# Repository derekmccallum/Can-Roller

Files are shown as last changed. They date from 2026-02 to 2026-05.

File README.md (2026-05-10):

# Can-Roller

Arduino driven device to roll up to 12 drink cans in unison for filming purposes

## Hardware

- 1 x Arduino CNC shield v3 with DRV8825 motor drivers
- 1 x Elegoo Uno R3
- 2 x HANPOSE 17HS4401-S 40mm Nema 17 Stepper Motor 42 Motor 42BYGH 1.7A 40N.cm 4-lead Motor
- 2 x GT2 2mm Pitch 6mm Width Closed Loop Synchronous Timing Belt 750 teeth 1500mm
- 2 x Machifit GT2 Timing Pulley 20 Teeth Synchronous Wheel Inner Diameter 5mm for 6mm Width Belt
- 4 x GT2 Idler Pulley 20 Teeth

## Control Input Features

| Feature | Ver | IO Pin | Description | Wiring |
|---|----|---|---|---|
| START button | v1 | A0 | If idle: start run (planned 5s total). If running: cancel and ramp down smoothly from current speed, then stop | Buttons wired to GND, use INPUT_PULLUP (pressed = LOW) |
| REVERSE button | v1 | A1 | Toggles travel direction | Buttons wired to GND, use INPUT_PULLUP (pressed = LOW) |
| SPEED pot | v1 | A2 | Sets cruise step rate | 5V → end, A2 → wiper, GND → other end |
| RUNTIME pot | v2 | A3 | Sets run time | 5V → end, A3 → wiper, GND → other end |

## File Versions
| File - Version | Description |
|---|---|
| can-roller-v1.ino | UNO + CNC Shield V3 + (2x) DRV8825<br>- START button (A0):<br>&nbsp;&nbsp;&nbsp;&nbsp;* if idle: start run (according to set runtime)<br>&nbsp;&nbsp;&nbsp;&nbsp;* if running: cancel and ramp down smoothly from CURRENT speed, then stop<br>- REVERSE button (A1): toggles direction for NEXT run only<br>- SPEED pot (A2): read once at start, sets cruise steps/sec (no mid-run updates)<br>- Soft start/stop: 0.5s ramp up / 0.5s ramp down<br>- DDS/phase-accumulator stepping (smooth, low jitter)<br>Buttons wired to GND, using INPUT_PULLUP (pressed = LOW) |
| can-roller-v2.ino | **New Feature: Variable Runtime Control**<br>- Added **RUNTIME pot** on analog pin **A3** for adjustable run duration (3-10 seconds)<br>- Runtime is read and latched when START button is pressed<br>- Replaces fixed 8-second duration from Version 1<br><br>**Hardware Change:**<br>- Add potentiometer to A3 (wired same as other pots: 5V → end, A3 → wiper, GND → other end)<br><br>**Control Summary:**<br>**A0**: START button - starts run or cancels mid-run<br>**A1**: REVERSE button - toggles direction for next run<br>**A2**: SPEED pot - read once at start, sets cruise (1000-9500 steps/sec)<br>**A3**: RUNTIME pot - sets run duration (3-10 seconds) ⭐ NEW<br><br>All other features unchanged: 0.5s soft start/stop, DDS stepping, smooth cancellation. |
| can-roller-v3.ino | **New Feature: Cruise speed variation during runtime**<br>1. Multi-Layer Noise Filtering:<br>Implemented moving average filter (5 samples) - smooths out electrical noise spikes<br>Rate limiting (2000 steps/sec² max change) - prevents sudden jerks from pot movements<br>Periodic sampling (every 50ms) - reduces ADC noise impact.<br><br>2. How It Works:<br>Raw Pot → Moving Average → Rate Limiter → Motor Speed<br>  (noisy) (smoothed) (gradual) (smooth)<br><br>**Control Summary:**<br>**A0**: START button - starts run or cancels mid-run<br>**A1**: REVERSE button - toggles direction for next run<br>**A2**: SPEED pot - sets cruise (1000-9500 steps/sec)<br>**A3**: RUNTIME pot - sets run duration (3-10 seconds)<br><br>All other features unchanged: 0.5s soft start/stop, DDS stepping, smooth cancellation. |
| can-roller-v4.ino | **New Feature: Dynamic reverse while running**<br>- REVERSE button behavior updated on **A1**:<br>&nbsp;&nbsp;&nbsp;&nbsp;* If idle: toggles direction for the next run only<br>&nbsp;&nbsp;&nbsp;&nbsp;* If running: performs normal ramp-down, toggles direction, waits a defined period, then restarts with normal ramp-up<br>- START button behavior unchanged: start when idle, graceful cancel when running<br>- SPEED (A2) and RUNTIME (A3) behavior unchanged from v3<br><br>Maintains soft start/stop profile and DDS stepping while adding in-run direction change handling. |
CNC Shield v3

## Power & step config

12V: 1/8 micro-stepping
Set jumpers MS1 ON, MS2 ON, MS3 OFF → 1600 steps/rev

	• DRV8825 @ 1/8 microstepping ⇒ 1600 steps/rev (200 × 8)
	• Can diameter ≈ 66 mm ⇒ circumference C ≈ 207.35 mm
	• GT2 pitch = 2 mm ⇒ belt travel per motor rev = 2 × teeth (mm)
	• Ideal no-slip rolling (and cans are constrained from translating)

Motor speed from step rate (independent of pulley teeth):
	• At 1000 steps/s: motor = 1000/1600 = 0.625 rps
	• At 9500 steps/s: motor = 9500/1600 = 5.9375 rps

Belt speed = motor_rps × (2×teeth)
Can speed (rev/s) = belt_speed / 207.35
 
A slave to X
	• Place a jumper on A → X

This electrically connects:
	• A_STEP → X_STEP
	• A_DIR  → X_DIR

So:
	• Both motors receive the same STEP and DIR signals
	• Arduino code only needs to drive X
	• A direction reversed owing to mounting

## DRV8825 Current Setting
### Configuration:
#### Stepper Motor: HANPOSE 17HS4401-S
• Rated Current: 1.7A per phase<br>
• Holding Torque: 40 N·cm (0.4 N·m)<br>
• Type: 4-lead bipolar<br>

#### DRV8825 Driver:
Vref measured (from pot centre arm to Gnd): 0.7V<br>
Current sense resistors: 0.1Ω (standard on most DRV8825 boards)

### Calculated Current Output:
Using the DRV8825 formula:<br>
Current Limit = Vref / (8 × Rs)<br>
Where:<br>
• Vref = 0.7V (your measurement)<br>
• Rs = 0.1Ω (sense resistor value)<br>

Current = 0.7V / (8 × 0.1Ω) = 0.875A

### Analysis:
✅ Safe Configuration
The motor is rated for 1.7A, and we're running it at 0.875A (≈51% of rated current).<br>
Pros:<br>
• Motors run cooler<br>
• Reduced risk of overheating<br>
• Longer motor life<br>
• Adequate torque for most applications<br>

Cons:<br>
• Not using full torque potential<br>
• May skip steps under heavy load<br>

### Current Setting Options:
#### Option 1: Keep Current Setting (Recommended for your application)
Vref = 0.7V → 0.875A

Good for belt-driven systems with moderate load<br>
Cooler operation<br>
Rolling cans shouldn't require full torque

#### Option 2: Increase to 70% rated current
Target: 1.19A<br>
Vref = Current × 8 × Rs<br>
Vref = 1.19 × 8 × 0.1 = 0.952V<br>
Adjust pot to 0.95V for more torque reserve<br>

#### Option 3: Maximum safe current (80% rated)<br>
Target: 1.36A<br>
Vref = 1.36 × 8 × 0.1 = 1.088V<br>
Adjust pot to ≈1.1V for maximum torque<br>

Warning: Motors will run hotter<br>
May need heatsinks or active cooling<br>

### Recommended Setting for this application:
Keep at 0.7V (0.875A) unless we experience:<br>
• Belt slipping under load<br>
• Motors skipping steps<br>
• Insufficient torque to move cans smoothly<br>

If you need more torque, increase to 0.85-0.95V (1.06-1.19A) and monitor motor temperature.

### How to Adjust (if needed):
Power off system<br>
Locate tiny potentiometer on DRV8825<br>
Connect multimeter:<br>
Black probe → GND<br>
Red probe → metal screwdriver touching pot wiper<br>

Power on (no motor movement needed)<br>
Turn pot slowly while monitoring voltage<br>
Clockwise = increase, Counter-clockwise = decrease<br>
Power off before removing multimeter<br>

### Temperature Check:
After running for 5-10 minutes, motors should be:<br>
• Warm to touch: Normal (40-50°C)<br>
• Hot but holdable (2+ seconds): Acceptable (50-70°C)<br>
• Too hot to hold: Too high (>70°C) - reduce current<br>

Your 0.7V setting should keep motors comfortably warm, not hot.

## Potentiometer Filter
Hardware fix for noisy analog potentiometer.

### Connection order:
1. Pot wiper → one leg of 1kΩ resistor<br>
2. Other leg of 1kΩ resistor → splits to:<br>
   • Arduino pin A2 / A3<br>
   • One leg of 100nF capacitor<br>
3. Other leg of 100nF capacitor → GND<br>

The junction point (where the resistor, Ax, and capacitor meet) is key - that's where the filtered signal sits.
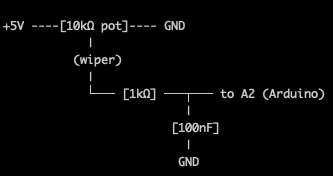
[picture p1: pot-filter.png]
Pot Filter Circuit


We're actually using 1.5kΩ resistor which is fine.<br>

### Why This Works:
• The capacitor forms a low-pass filter that removes high-frequency electrical noise<br>
• The code already averages 10 samples, so the capacitor won't make the response too sluggish<br>
• Ceramic caps are non-polarized, so orientation doesn't matter<br>

### What's the Point of the 1kΩ Resistor?
• Creates a Proper Low-Pass Filter:<br>
• The resistor + capacitor form an RC low-pass filter with a specific cutoff frequency:<br>
• Cutoff frequency = 1 / (2π × R × C)<br>

### With 1kΩ and 100nF: ~1.6 kHz cutoff
This blocks noise above 1.6 kHz while passing your slow pot movements

### Why It's Better Than Capacitor Alone:
Prevents ADC Input Loading: The capacitor directly on the ADC input can cause issues because the Arduino's ADC has internal resistance (~10kΩ). The 1kΩ resistor isolates this.<br>
More Predictable Filtering: Without the resistor, the filter behavior depends on the pot position (pot resistance varies as you turn it). The 1kΩ makes filtering consistent.<br>
Reduces High-Frequency Noise: The resistor limits current spikes when the cap charges/discharges, providing cleaner filtering.<br>

## Appendix
### Pulley Specs

20T pulley
Belt per rev: 40 mm

	• 1000 steps/s
		○ Belt speed: 0.625 × 40 = 25.0 mm/s
		○ Can speed: 25.0 / 207.35 = 0.1206 rps = 7.23 RPM
		○ Time per turn: 8.29 s/rev
	• 9500 steps/s
		○ Belt speed: 5.9375 × 40 = 237.5 mm/s
		○ Can speed: 237.5 / 207.35 = 1.1454 rps = 68.73 RPM
		○ Time per turn: 0.873 s/rev

24T pulley
Belt per rev: 48 mm

	• 1000 steps/s
		○ Belt speed: 0.625 × 48 = 30.0 mm/s
		○ Can speed: 30.0 / 207.35 = 0.1447 rps = 8.68 RPM
		○ Time per turn: 6.91 s/rev
	• 9500 steps/s
		○ Belt speed: 5.9375 × 48 = 285.0 mm/s
		○ Can speed: 285.0 / 207.35 = 1.3745 rps = 82.47 RPM
		○ Time per turn: 0.728 s/rev

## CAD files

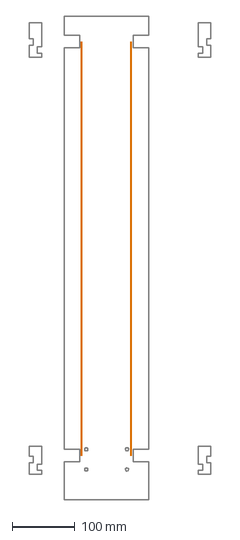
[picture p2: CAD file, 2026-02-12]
can roller base.dxf
289.7 x 770.0 mm

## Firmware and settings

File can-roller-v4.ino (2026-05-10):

/*
  UNO + CNC Shield V3 + (2x) DRV8825
  - START button (A0):
      * if idle: start run (planned duration set by RUNTIME pot)
      * if running: cancel and ramp down smoothly from CURRENT speed, then stop
  - REVERSE button (A1):
      * if idle: toggles direction for NEXT run only
      * if running: ramp down, toggle direction, wait for period defined in REVERSE_RESTART_DELAY_MS, then ramp up again
  - SPEED pot (A2): continuously read during run with filtering for smooth speed changes
  - RUNTIME pot (A3): read once at start, sets run duration 3-10 seconds
  - Soft start/stop: 0.5s ramp up / 0.5s ramp down
  - DDS/phase-accumulator stepping (smooth, low jitter)
  - Real-time speed adjustment with non-blocking reads

  Buttons wired to GND, using INPUT_PULLUP (pressed = LOW)
*/

#include <Arduino.h>

// CNC Shield V3 (typical)
const uint8_t X_STEP = 2;
const uint8_t X_DIR  = 5;
const uint8_t A_STEP = 12;
const uint8_t A_DIR  = 13;
const uint8_t EN_PIN = 8;

// Inputs
const uint8_t PIN_START   = A0;
const uint8_t PIN_REVERSE = A1;
const uint8_t PIN_POT     = A2;
const uint8_t PIN_RUNTIME = A3;

// Timing / profile
const uint16_t RAMP_MS = 500;
const uint16_t MIN_STEPS_PER_SEC = 200;

// Runtime mapping (milliseconds)
const uint32_t MIN_RUNTIME_MS = 3000;   // 3 seconds
const uint32_t MAX_RUNTIME_MS = 10000;  // 10 seconds

// Pot mapping
const uint16_t POT_MIN_STEPS_PER_SEC = 1000;
const uint16_t POT_MAX_STEPS_PER_SEC = 9500;

// Real-time speed reading - NON-BLOCKING
const uint16_t SPEED_READ_INTERVAL_MS = 100;  // Read pot every 100ms
const uint8_t SPEED_FILTER_SAMPLES = 8;       // Moving average window

// Speed change rate limiting (steps/sec per second)
const uint16_t MAX_SPEED_CHANGE_RATE = 3000; // Max 3000 steps/sec change per second

// DRV8825 pulse width
const uint8_t STEP_PULSE_US = 6;

// Debounce
const uint16_t DEBOUNCE_MS = 30;

// Reverse direction pause between ramp-down and restart
const uint16_t REVERSE_RESTART_DELAY_MS = 130;

// State machine
enum RunState : uint8_t { IDLE, RAMP_UP, CRUISE, RAMP_DOWN };
RunState state = IDLE;

bool nextRunForward = true;
bool reverseRestartPending = false;     // Reverse pressed while running; waiting to finish ramp-down
bool reverseWaitActive = false;         // Pause after direction toggle before restart
uint32_t reverseWaitStartMs = 0;

uint16_t targetStepsPerSec = 2000;     // Target speed (filtered from pot)
uint16_t rampDownStartRate = 0;        // Captured instantaneous rate at ramp-down start
uint32_t plannedRunMs = 8000;          // Latched runtime at start

uint32_t runStartMs = 0;               // When run began (for planned duration)
uint32_t phaseStartMs = 0;             // When current phase began
uint32_t lastMicros = 0;
uint32_t lastSpeedReadMs = 0;          // Last time we read the speed pot

uint64_t accumUnits = 0;               // DDS accumulator

// Speed filtering - simple moving average
uint32_t speedAccumulator = 0;         // Running sum for average
uint16_t speedHistory[SPEED_FILTER_SAMPLES];
uint8_t speedHistoryIndex = 0;
bool speedHistoryFilled = false;

// ---- helpers ----
static inline void stepBothOnce() {
  digitalWrite(X_STEP, HIGH);
  digitalWrite(A_STEP, HIGH);
  delayMicroseconds(STEP_PULSE_US);
  digitalWrite(X_STEP, LOW);
  digitalWrite(A_STEP, LOW);
}

static inline uint16_t lerp_u16(uint16_t a, uint16_t b, uint32_t num, uint32_t den) {
  if (den == 0) return b;
  int32_t diff = (int32_t)b - (int32_t)a;
  int32_t val  = (int32_t)a + (diff * (int32_t)num) / (int32_t)den;
  if (val < 1) val = 1;
  return (uint16_t)val;
}

struct DebouncedButton {
  uint8_t pin;
  bool stableState;
  bool lastStableState;
  uint32_t lastChangeMs;

  void begin(uint8_t p) {
    pin = p;
    stableState = digitalRead(pin);
    lastStableState = stableState;
    lastChangeMs = millis();
  }

  bool pressedEvent() {
    bool raw = digitalRead(pin);
    uint32_t now = millis();

    if (raw != stableState) {
      if (now - lastChangeMs >= DEBOUNCE_MS) {
        lastStableState = stableState;
        stableState = raw;
        lastChangeMs = now;
        return (lastStableState == HIGH && stableState == LOW);
      }
    } else {
      lastChangeMs = now;
    }
    return false;
  }
};

DebouncedButton btnStart;
DebouncedButton btnReverse;

// Read speed pot with basic averaging (BLOCKING - only use at start)
uint16_t readSpeedFromPotBlocking() {
  uint32_t sum = 0;
  const uint8_t samples = 10;
  for (uint8_t i = 0; i < samples; i++) {
    sum += analogRead(PIN_POT);
    delayMicroseconds(900);
  }
  uint16_t v = (uint16_t)(sum / samples); // 0..1023

  uint32_t rate = (uint32_t)POT_MIN_STEPS_PER_SEC +
                  ((uint32_t)(POT_MAX_STEPS_PER_SEC - POT_MIN_STEPS_PER_SEC) * v) / 1023UL;

  if (rate < MIN_STEPS_PER_SEC) rate = MIN_STEPS_PER_SEC;
  if (rate > 65000) rate = 65000;
  return (uint16_t)rate;
}

// Read speed pot - SINGLE SAMPLE, non-blocking
uint16_t readSpeedFromPotFast() {
  uint16_t v = analogRead(PIN_POT); // Single read, ~100us

  uint32_t rate = (uint32_t)POT_MIN_STEPS_PER_SEC +
                  ((uint32_t)(POT_MAX_STEPS_PER_SEC - POT_MIN_STEPS_PER_SEC) * v) / 1023UL;

  if (rate < MIN_STEPS_PER_SEC) rate = MIN_STEPS_PER_SEC;
  if (rate > 65000) rate = 65000;
  return (uint16_t)rate;
}

// Read runtime from pot on A3 (BLOCKING - only at start)
uint32_t readRuntimeFromPot() {
  uint32_t sum = 0;
  const uint8_t samples = 10;
  for (uint8_t i = 0; i < samples; i++) {
    sum += analogRead(PIN_RUNTIME);
    delayMicroseconds(900);
  }
  uint16_t v = (uint16_t)(sum / samples); // 0..1023

  uint32_t runtime = MIN_RUNTIME_MS +
                     ((MAX_RUNTIME_MS - MIN_RUNTIME_MS) * (uint32_t)v) / 1023UL;

  return runtime;
}

// Initialize speed filter with a value
void initSpeedFilter(uint16_t initialSpeed) {
  speedAccumulator = (uint32_t)initialSpeed * SPEED_FILTER_SAMPLES;
  for (uint8_t i = 0; i < SPEED_FILTER_SAMPLES; i++) {
    speedHistory[i] = initialSpeed;
  }
  speedHistoryIndex = 0;
  speedHistoryFilled = true;
}

// Add sample to moving average filter - OPTIMIZED
uint16_t filterSpeed(uint16_t newSpeed) {
  // Subtract oldest value from accumulator
  speedAccumulator -= speedHistory[speedHistoryIndex];
  
  // Add new value
  speedHistory[speedHistoryIndex] = newSpeed;
  speedAccumulator += newSpeed;
  
  speedHistoryIndex = (speedHistoryIndex + 1) % SPEED_FILTER_SAMPLES;
  if (speedHistoryIndex == 0) speedHistoryFilled = true;

  // Return average
  return (uint16_t)(speedAccumulator / SPEED_FILTER_SAMPLES);
}

// Apply rate limiting to speed changes
uint16_t rateLimitSpeed(uint16_t target, uint16_t current, uint32_t dtMs) {
  if (dtMs == 0) return current;
  
  int32_t diff = (int32_t)target - (int32_t)current;
  int32_t maxChange = ((int32_t)MAX_SPEED_CHANGE_RATE * (int32_t)dtMs) / 1000;
  
  if (diff > maxChange) {
    return current + (uint16_t)maxChange;
  } else if (diff < -maxChange) {
    return current - (uint16_t)maxChange;
  } else {
    return target;
  }
}

// Update target speed from pot during cruise (called periodically)
// NON-BLOCKING - single fast ADC read
void updateTargetSpeed(uint32_t nowMs) {
  if (state != CRUISE) return;
  if (nowMs - lastSpeedReadMs < SPEED_READ_INTERVAL_MS) return;
  
  uint32_t dtMs = nowMs - lastSpeedReadMs;
  lastSpeedReadMs = nowMs;
  
  // FAST single sample read (~100us)
  uint16_t rawSpeed = readSpeedFromPotFast();
  
  // Apply moving average filter
  uint16_t filteredSpeed = filterSpeed(rawSpeed);
  
  // Apply rate limiting
  targetStepsPerSec = rateLimitSpeed(filteredSpeed, targetStepsPerSec, dtMs);
}

void enableDrivers()  { digitalWrite(EN_PIN, LOW); }
void disableDrivers() { digitalWrite(EN_PIN, HIGH); }

// Returns the instantaneous commanded rate *for the current state* without changing state.
uint16_t instantaneousRateNow(uint32_t nowMs) {
  switch (state) {
    case RAMP_UP: {
      uint32_t t = nowMs - phaseStartMs;
      if (t >= RAMP_MS) return targetStepsPerSec;
      return lerp_u16(MIN_STEPS_PER_SEC, targetStepsPerSec, t, RAMP_MS);
    }
    case CRUISE:
      return targetStepsPerSec;

    case RAMP_DOWN: {
      // ramp from rampDownStartRate -> MIN over RAMP_MS
      uint32_t t = nowMs - phaseStartMs;
      if (t >= RAMP_MS) return 0;
      return lerp_u16(MIN_STEPS_PER_SEC, rampDownStartRate, (RAMP_MS - t), RAMP_MS);
    }

    case IDLE:
    default:
      return 0;
  }
}

void beginRun() {
  targetStepsPerSec = readSpeedFromPotBlocking();  // Blocking read at start is fine
  plannedRunMs = readRuntimeFromPot();
  
  // Initialize speed filter with starting speed
  initSpeedFilter(targetStepsPerSec);

  digitalWrite(X_DIR, nextRunForward ? HIGH : LOW);
  digitalWrite(A_DIR, nextRunForward ? HIGH : LOW);

  enableDrivers();

  runStartMs = millis();
  phaseStartMs = runStartMs;
  lastMicros = micros();
  lastSpeedReadMs = runStartMs;
  accumUnits = 0;

  state = RAMP_UP;
}

void beginRampDownFromCurrent() {
  if (state == IDLE) return;

  uint32_t nowMs = millis();
  uint16_t current = instantaneousRateNow(nowMs);

  // Make sure we don't start below MIN (keeps ramp math sensible)
  if (current < MIN_STEPS_PER_SEC) current = MIN_STEPS_PER_SEC;

  rampDownStartRate = current;
  state = RAMP_DOWN;
  phaseStartMs = nowMs;
}

void endRun() {
  disableDrivers();   // comment out if you want hold torque
  state = IDLE;
}

// Advances state machine and returns commanded rate for this moment.
// This may transition from RAMP_UP->CRUISE or CRUISE->RAMP_DOWN automatically.
uint16_t commandedRate() {
  uint32_t nowMs = millis();

  switch (state) {
    case RAMP_UP: {
      uint32_t t = nowMs - phaseStartMs;
      if (t >= RAMP_MS) {
        state = CRUISE;
        phaseStartMs = nowMs;
        lastSpeedReadMs = nowMs;  // Reset speed read timer
        return targetStepsPerSec;
      }
      return lerp_u16(MIN_STEPS_PER_SEC, targetStepsPerSec, t, RAMP_MS);
    }

    case CRUISE: {
      // Update target speed from pot (non-blocking single read)
      updateTargetSpeed(nowMs);
      
      // Start ramp-down automatically so planned run time includes ramp-down.
      uint32_t elapsed = nowMs - runStartMs;
      uint32_t cruiseUntil = (plannedRunMs > RAMP_MS) ? (plannedRunMs - RAMP_MS) : 0;

      if (elapsed >= cruiseUntil) {
        // ramp down from current cruise speed
        rampDownStartRate = targetStepsPerSec;
        state = RAMP_DOWN;
        phaseStartMs = nowMs;
        return targetStepsPerSec;
      }
      return targetStepsPerSec;
    }

    case RAMP_DOWN: {
      uint32_t t = nowMs - phaseStartMs;
      if (t >= RAMP_MS) {
        endRun();
        return 0;
      }
      return lerp_u16(MIN_STEPS_PER_SEC, rampDownStartRate, (RAMP_MS - t), RAMP_MS);
    }

    case IDLE:
    default:
      return 0;
  }
}

void setup() {
  pinMode(X_STEP, OUTPUT);
  pinMode(X_DIR, OUTPUT);
  pinMode(A_STEP, OUTPUT);
  pinMode(A_DIR, OUTPUT);
  pinMode(EN_PIN, OUTPUT);

  pinMode(PIN_START, INPUT_PULLUP);
  pinMode(PIN_REVERSE, INPUT_PULLUP);

  disableDrivers();

  btnStart.begin(PIN_START);
  btnReverse.begin(PIN_REVERSE);
}

void loop() {
  // Handle delayed restart after reverse-while-running workflow
  if (reverseWaitActive) {
    if (millis() - reverseWaitStartMs >= REVERSE_RESTART_DELAY_MS) {
      reverseWaitActive = false;
      beginRun();
    } else {
      return;
    }
  }

  // Reverse behavior:
  // - if idle: toggle direction for next run
  // - if running: ramp down, toggle, pause, then restart
  if (btnReverse.pressedEvent()) {
    if (state == IDLE) {
      nextRunForward = !nextRunForward;
    } else if (!reverseRestartPending) {
      reverseRestartPending = true;
      beginRampDownFromCurrent();
    }
  }

  // START toggles: start if idle; cancel (graceful) if running
  if (btnStart.pressedEvent()) {
    if (state == IDLE) beginRun();
    else beginRampDownFromCurrent();
  }

  if (state == IDLE) return;

  // Get commanded rate for this moment (may advance state)
  uint16_t rate = commandedRate();
  if (state == IDLE || rate == 0) {
    if (state == IDLE && reverseRestartPending) {
      reverseRestartPending = false;
      nextRunForward = !nextRunForward;
      reverseWaitActive = true;
      reverseWaitStartMs = millis();
    }
    return;
  }

  // DDS stepping using elapsed micros
  uint32_t nowUs = micros();
  uint32_t dtUs = (uint32_t)(nowUs - lastMicros);
  lastMicros = nowUs;

  accumUnits += (uint64_t)rate * (uint64_t)dtUs;

  while (accumUnits >= 1000000ULL) {
    accumUnits -= 1000000ULL;
    stepBothOnce();
  }
}

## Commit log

2026-02-12 Implement CNC control logic for UNO with DRV8825
    Initial implementation of CNC control for UNO with DRV8825 drivers, including start, reverse, and speed control functionalities.
    [can-roller-v1.ino]
2026-02-12 Update README with component specifications and wiring
    Added detailed specifications and wiring instructions for components.
2026-02-12 Expand README with power and step config details
    Added power and step configuration details, including motor speed calculations and pulley specifications.
2026-02-12 Add files via upload
    5mm Ply Template
    [can roller base.dxf]
2026-02-12 Correct motor driver model in README
    Updated hardware specifications for the Arduino project.
2026-02-13 Implement runtime control via potentiometer
    Added functionality to read runtime from a potentiometer on pin A3 and updated the run logic to incorporate planned runtime.
2026-03-05 Implement noise filtering for motor speed control
    Added multi-layer noise filtering for motor speed control, including moving average filtering, rate limiting, and periodic sampling to improve stability and responsiveness.
    [can-roller-v3.ino]
2026-03-05 Add DRV8825 current setting documentation
    Added DRV8825 current setting documentation with configuration details, calculated current output, analysis, current setting options, and adjustment instructions.
2026-03-05 Optimize speed reading and filtering methods
2026-03-05 Revise feature descriptions in README.md
    Updated descriptions for REVERSE button, SPEED pot, and RUNTIME pot in the features table.
2026-03-05 Update README with potentiometer filter details
    Added documentation for potentiometer filter and its benefits.
2026-03-05 Add Pot Filter Circuit diagram to README
    Added a diagram of the Pot Filter Circuit to the README.
2026-03-05 Update README with resistor specifications and explanation
2026-03-06 Update README with capacitor and resistor explanations
2026-05-06 New can-roller-v4.ino implementing reverse during run
    [can-roller-v4.ino]
2026-05-10 Implement adjustable variable for delay between reverse ramp-down and ramp-up when run active.
    [can-roller-v4.ino]
2026-05-10 Update REVERSE button behavior during running state
    [can-roller-v4.ino]
2026-10-16 Add v5 X-only stepper drive
2026-10-20 Fix DDS burst stepping: while -> if in step loop
    Multiple steps firing per loop() iteration caused instantaneous step
    rates far above the commanded rate, producing motor clicking/stalls.
    The same burst caused positionSteps to jump past the ramp-down trigger
    threshold, so endRun() fired directly from the DDS loop at cruise speed
    instead of triggering a graceful ramp-down.
    Replacing while with if ensures at most one step per loop() call;
    the accumulator carries the remainder forward as intended. Replace
    the now-invalid break statements with return / fall-through.
2026-10-20 Fix abrupt stop and revert incorrect while->if change
    Two fixes:
    1. Revert while->if in DDS loop (previous commit was wrong).
    The DDS requires while to drain all accumulated steps; with if,
    the loop speed caps the effective step rate, causing the speed
    to chop and vary as observed.
    2. Fix CRUISE->RAMP_DOWN transition when already at aligned position.
    beginRampDownFromCurrent(true) was always passed, even when
    remainingAlignedStopSteps()==0 (motor exactly on a rotation
    boundary at end of run). aligningToPositionStop=true with
    remaining=0 caused commandedRate() RAMP_DOWN to call endRun()
    on its very first call — abrupt stop at full cruise speed.
    Fix: cache remain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
2026-10-20 Fix clicking/oscillation: move aligned-stop checks out of DDS loop
    v5 had no logic inside the DDS while loop beyond decrement+step.
    v6 added two calls to remainingAlignedStopSteps() per iteration;
    each involves a 32-bit modulo on AVR (~100+ cycles each = 6-12us),
    injecting 20-30us of jitter into inter-step timing and causing
    motor resonance/clicking.
    Move both checks outside the while loop. A burst is at most 1-2
    steps, so checking once after the loop is equivalent. Max overshoot
    of an aligned boundary is 1 step = 0.043 degrees at 8300 steps/rev.
2026-10-20 Eliminate 32-bit modulo from hot DDS loop to fix oscillation
    stepsToNextAlignedPosition() called positionSteps % selectedStepsPerCanRev
    on every loop iteration. On a 16MHz AVR with no hardware divider this is
    a ~200-cycle software divide (~12us). Called twice per loop (CRUISE check
    + post-while check) it added ~24us of jitter to inter-step timing,
    causing motor oscillation absent in v5.
    Fix: maintain posModRev incrementally in the DDS while loop using
    increment-and-wrap (forward) or decrement-and-wrap (reverse). Each step
    updates posModRev in ~3 cycles instead of ~200. stepsToNextAlignedPosition
    now reads posModRev directly with no division.
2026-10-20 Fix v6 oscillation: eliminate division from CRUISE hot loop
    Three changes to remove per-loop division overhead that v5 never had:
    1. remainingAlignedStopSteps(): fast early-out when more than one full
    rotation from target (returns targetRunSteps-stepsThisRun with no
    division). The extraRotations ceiling-divide only runs in the final
    rotation — not every loop throughout the run.
    2. CRUISE commandedRate: pre-filter on stepsThisRun before calling either
    remainingAlignedStopSteps() or rampStepEstimate(). For all but the
    last 3000 steps (the entire run minus ~2 rotations) the CRUISE check
    costs only a single 32-bit add+compare, matching v5's overhead.
    3. RAMP_DOWN and post-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
2026-10-20 A5 switch position: disable position-aligned stop, use time-based stop
    selectedCanDiameterFromSwitch() returns 0 for A5 as a sentinel meaning
    'no alignment'. beginRun() treats 0 as: positionStopActive=false,
    selectedStepsPerCanRev=0, targetRunSteps=0 (all unused).
    CRUISE: else-if branch for !positionStopActive restores the v5 elapsed-
    time ramp trigger (plannedRunMs - RAMP_MS). Since positionStopActive is
    false, all aligned-stop checks are already gated off elsewhere, so
    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
2026-10-20 Update README: A5 switch position is now time-based stop, not a third can size
2026-10-21 Use longer ramp for slim can to reduce belt slip
    250 ml slim can slips ~3 mm during ramp-up at high speed because it is
    lighter and sits with less contact force against the belt. The 400 ml can
    is unaffected.
    Introduce RAMP_MS_SLIM = 1000 ms alongside the existing RAMP_MS = 500 ms.
    beginRun() selects the appropriate value into activeRampMs based on the
    can-size switch. All runtime ramp logic (rampStepEstimate, plannedStepEstimate,
    instantaneousRateNow, commandedRate) uses activeRampMs, so the softer
    acceleration profile is applied consistently and the aligned stop step
    target is recalculated correctly for the longer ramp shape.
2026-10-21 Add GT2 Drive Pulley to components list
2026-10-21 Update components list in README.md
    Removed duplicate GT2 drive pulley and updated timing belt entry.
